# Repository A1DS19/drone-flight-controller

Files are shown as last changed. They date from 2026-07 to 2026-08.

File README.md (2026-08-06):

# Drone Flight Controller

A custom drone flight controller, designed in KiCad 10: an STM32F103R8T6 flight core paired with
an ATmega328P telemetry co-processor on a four-layer, ~102 × 49 mm PCB — taken from schematic
capture through placement, routing, clean ERC/DRC, and JLCPCB fabrication outputs
([pcb/production/](pcb/production/)).

## Features

- **STM32F103R8T6 flight core** — MPU-6050 IMU on I²C, four ESC/motor outputs, RC-receiver and
  TF-Luna LIDAR inputs, USB with ESD protection, SWD debug
- **ATmega328P telemetry co-processor** — nRF24L01P 2.4 GHz radio with SMA antenna connector,
  CH340G USB-serial, microSD logging over SPI, 5 V ↔ 3.3 V level shifting
- **Power tree** — XT60 battery input → LM7805 (5 V) → AMS1117 (3.3 V), filtered analog rail,
  battery-voltage sensing
- **0.96″ OLED** status display
- **Four-layer board** — solid internal ground plane, dedicated power planes, 71-line LCSC BOM,
  JLCPCB-ready Gerbers

## Screenshots

| Front | Back |
|---|---|
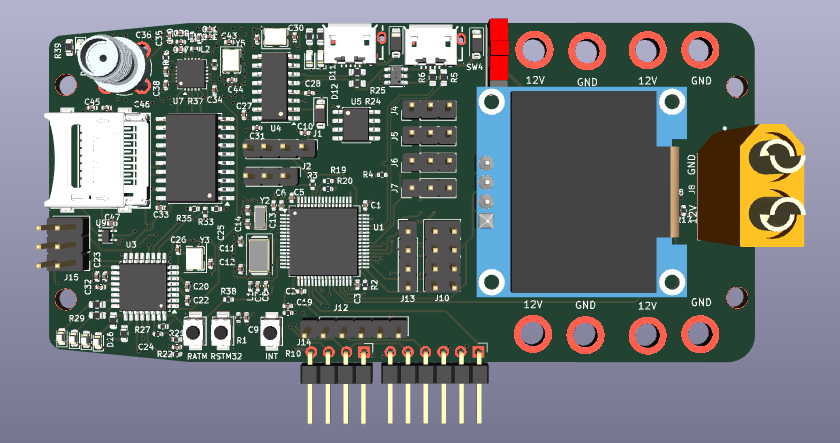
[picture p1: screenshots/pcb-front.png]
Board front
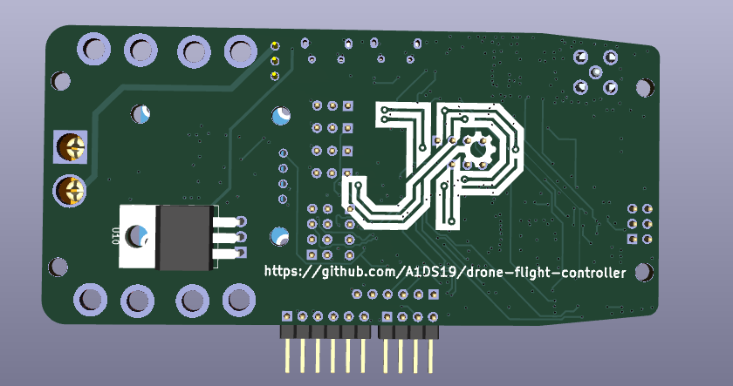
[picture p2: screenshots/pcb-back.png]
Board back
|  |  |

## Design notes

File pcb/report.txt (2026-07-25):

Info: Processing symbol 'R3:Resistor_SMD:R_0402_1005Metric'.
Info: Processing symbol 'U11:Package_TO_SOT_SMD:SOT-223-3_TabPin2'.
Info: Processing symbol 'U10:Package_TO_SOT_THT:TO-220-3_Horizontal_TabDown'.
Info: Processing symbol 'J17:easyeda:SMA_142-0701-201'.
Info: Processing symbol 'L1:Inductor_SMD:L_0402_1005Metric'.
Info: Processing symbol 'L2:Inductor_SMD:L_0402_1005Metric'.
Info: Processing symbol 'L3:Inductor_SMD:L_0402_1005Metric'.
Info: Processing symbol 'L4:Inductor_SMD:L_0402_1005Metric'.
Info: Processing symbol 'R1:Resistor_SMD:R_0402_1005Metric'.
Info: Processing symbol 'R2:Resistor_SMD:R_0402_1005Metric'.
Info: Processing symbol 'Y1:Crystal:Crystal_SMD_5032-2Pin_5.0x3.2mm'.
Info: Processing symbol 'R4:Resistor_SMD:R_0402_1005Metric'.
Info: Processing symbol 'R5:Resistor_SMD:R_0402_1005Metric'.
Info: Processing symbol 'R6:Resistor_SMD:R_0402_1005Metric'.
Info: Processing symbol 'R7:Resistor_SMD:R_0402_1005Metric'.
Info: Processing symbol 'R8:Resistor_SMD:R_0402_1005Metric'.
Info: Processing symbol 'R9:Resistor_SMD:R_0402_1005Metric'.
Info: Processing symbol 'R10:Resistor_SMD:R_0402_1005Metric'.
Info: Processing symbol 'R11:Resistor_SMD:R_0603_1608Metric'.
Info: Processing symbol 'R12:Resistor_SMD:R_0603_1608Metric'.
Info: Processing symbol 'J8:easyeda:AMASS_XT60-M'.
Info: Processing symbol 'J3:easyeda:MICRO-USB-SMD_MICROXNJ_1'.
Info: Processing symbol 'Y5:Crystal:Crystal_SMD_SeikoEpson_TSX3225-4Pin_3.2x2.5mm'.
Info: Processing symbol 'Y4:Crystal:Crystal_SMD_SeikoEpson_TSX3225-4Pin_3.2x2.5mm'.
Info: Processing symbol 'Y3:Crystal:Crystal_SMD_SeikoEpson_TSX3225-4Pin_3.2x2.5mm'.
Info: Processing symbol 'C1:Capacitor_SMD:C_0402_1005Metric'.
Info: Processing symbol 'J4:Connector_PinHeader_2.54mm:PinHeader_1x03_P2.54mm_Vertical'.
Info: Processing symbol 'J5:Connector_PinHeader_2.54mm:PinHeader_1x03_P2.54mm_Vertical'.
Info: Processing symbol 'J6:Connector_PinHeader_2.54mm:PinHeader_1x03_P2.54mm_Vertical'.
Info: Processing symbol 'J7:Connector_PinHeader_2.54mm:PinHeader_1x03_P2.54mm_Vertical'.
Info: Processing symbol 'R13:Resistor_SMD:R_0603_1608Metric'.
Info: Processing symbol 'J9:Connector_PinHeader_2.54mm:PinHeader_1x06_P2.54mm_Horizontal'.
Info: Processing symbol 'J10:Connector_PinHeader_2.54mm:PinHeader_2x04_P2.54mm_Vertical'.
Info: Processing symbol 'J11:easyeda:OLED'.
Info: Processing symbol 'J12:Connector_PinHeader_2.54mm:PinHeader_1x06_P2.54mm_Vertical'.
Info: Processing symbol 'J13:Connector_PinHeader_2.54mm:PinHeader_1x04_P2.54mm_Vertical'.
Info: Processing symbol 'J14:Connector_PinHeader_2.54mm:PinHeader_1x04_P2.54mm_Horizontal'.
Info: Processing symbol 'J15:Connector_PinHeader_2.54mm:PinHeader_2x03_P2.54mm_Vertical'.
Info: Processing symbol 'J16:easyeda:MICRO-USB-SMD_MICROXNJ_1'.
Info: Processing symbol 'Y2:Crystal:Crystal_SMD_3215-2Pin_3.2x1.5mm'.
Info: Processing symbol 'SW4:easyeda:SW-TH_SHOU-HAN_SS12D10G4'.
Info: Processing symbol 'R34:Resistor_SMD:R_0603_1608Metric'.
Info: Processing symbol 'R35:Resistor_SMD:R_0402_1005Metric'.
Info: Processing symbol 'R36:Resistor_SMD:R_0402_1005Metric'.
Info: Processing symbol 'R37:Resistor_SMD:R_0402_1005Metric'.
Info: Processing symbol 'R38:Resistor_SMD:R_0402_1005Metric'.
Info: Processing symbol 'R39:Resistor_SMD:R_0603_1608Metric'.
Info: Processing symbol 'SW1:Button_Switch_THT:SW_PUSH_6mm_H9.5mm'.
Info: Processing symbol 'SW2:Button_Switch_THT:SW_PUSH_6mm_H9.5mm'.
Info: Processing symbol 'SW3:Button_Switch_THT:SW_PUSH_6mm_H9.5mm'.
Info: Processing symbol 'R33:Resistor_SMD:R_0402_1005Metric'.
Info: Processing symbol 'U1:Package_QFP:LQFP-64_10x10mm_P0.5mm'.
Info: Processing symbol 'U2:Sensor_Motion:InvenSense_QFN-24_4x4mm_P0.5mm'.
Info: Processing symbol 'U3:Package_QFP:TQFP-32_7x7mm_P0.8mm'.
Info: Processing symbol 'U4:Package_SO:SOIC-16_3.9x9.9mm_P1.27mm'.
Info: Processing symbol 'U5:Package_SO:SOIC-8_3.9x4.9mm_P1.27mm'.
Info: Processing symbol 'U6:Package_SO:SOIC-20W_7.5x12.8mm_P1.27mm'.
Info: Processing symbol 'U7:Package_DFN_QFN:QFN-20-1EP_4x4mm_P0.5mm_EP2.5x2.5mm'.
Info: Processing symbol 'U9:Package_TO_SOT_SMD:SOT-353_SC-70-5'.
Info: Processing symbol 'U8:easyeda:TF-SMD_472192001'.
Info: Processing symbol 'R23:Resistor_SMD:R_0603_1608Metric'.
Info: Processing symbol 'R14:Resistor_SMD:R_0603_1608Metric'.
Info: Processing symbol 'R15:Resistor_SMD:R_0603_1608Metric'.
Info: Processing symbol 'R16:Resistor_SMD:R_0603_1608Metric'.
Info: Processing symbol 'R17:Resistor_SMD:R_0402_1005Metric'.
Info: Processing symbol 'R18:Resistor_SMD:R_0402_1005Metric'.
Info: Processing symbol 'R19:Resistor_SMD:R_0402_1005Metric'.
Info: Processing symbol 'R20:Resistor_SMD:R_0402_1005Metric'.
Info: Processing symbol 'R21:Resistor_SMD:R_0402_1005Metric'.
Info: Processing symbol 'R22:Resistor_SMD:R_0402_1005Metric'.
Info: Processing symbol 'J2:Connector_PinHeader_2.54mm:PinHeader_1x03_P2.54mm_Vertical'.
Info: Processing symbol 'R24:Resistor_SMD:R_0402_1005Metric'.
Info: Processing symbol 'R25:Resistor_SMD:R_0402_1005Metric'.
Info: Processing symbol 'R26:Resistor_SMD:R_0402_1005Metric'.
Info: Processing symbol 'R27:Resistor_SMD:R_0402_1005Metric'.
Info: Processing symbol 'R28:Resistor_SMD:R_0603_1608Metric'.
Info: Processing symbol 'R29:Resistor_SMD:R_0603_1608Metric'.
Info: Processing symbol 'R30:Resistor_SMD:R_0402_1005Metric'.
Info: Processing symbol 'R31:Resistor_SMD:R_0603_1608Metric'.
Info: Processing symbol 'R32:Resistor_SMD:R_0603_1608Metric'.
Info: Processing symbol 'C31:Capacitor_SMD:C_0402_1005Metric'.
Info: Processing symbol 'C22:Capacitor_SMD:C_0402_1005Metric'.
Info: Processing symbol 'C23:Capacitor_SMD:C_0402_1005Metric'.
Info: Processing symbol 'C24:Capacitor_SMD:C_0402_1005Metric'.
Info: Processing symbol 'C25:Capacitor_SMD:C_0402_1005Metric'.
Info: Processing symbol 'C26:Capacitor_SMD:C_0402_1005Metric'.
Info: Processing symbol 'C27:Capacitor_SMD:C_0402_1005Metric'.
Info: Processing symbol 'C28:Capacitor_SMD:C_0402_1005Metric'.
Info: Processing symbol 'C29:Capacitor_SMD:C_0402_1005Metric'.
Info: Processing symbol 'C30:Capacitor_SMD:C_0402_1005Metric'.
Info: Processing symbol 'C21:Capacitor_SMD:C_0402_1005Metric'.
Info: Processing symbol 'C32:Capacitor_SMD:C_0402_1005Metric'.
Info: Processing symbol 'C33:Capacitor_SMD:C_0402_1005Metric'.
Info: Processing symbol 'C34:Capacitor_SMD:C_0402_1005Metric'.
Info: Processing symbol 'C35:Capacitor_SMD:C_0402_1005Metric'.
Info: Processing symbol 'C36:Capacitor_SMD:C_0402_1005Metric'.
Info: Processing symbol 'C37:Capacitor_SMD:C_0402_1005Metric'.
Info: Processing symbol 'C38:Capacitor_SMD:C_0402_1005Metric'.
Info: Processing symbol 'C39:Capacitor_SMD:C_0402_1005Metric'.
Info: Processing symbol 'C40:Capacitor_SMD:C_0402_1005Metric'.
Info: Processing symbol 'C11:Capacitor_SMD:C_0402_1005Metric'.
Info: Processing symbol 'C2:Capacitor_SMD:C_0402_1005Metric'.
Info: Processing symbol 'C3:Capacitor_SMD:C_0402_1005Metric'.
Info: Processing symbol 'C4:Capacitor_SMD:C_0402_1005Metric'.
Info: Processing symbol 'C5:Capacitor_SMD:C_0402_1005Metric'.
Info: Processing symbol 'C6:Capacitor_SMD:C_0402_1005Metric'.
Info: Processing symbol 'C7:Capacitor_SMD:C_0402_1005Metric'.
Info: Processing symbol 'C8:Capacitor_SMD:C_0402_1005Metric'.
Info: Processing symbol 'C9:Capacitor_SMD:C_0402_1005Metric'.
Info: Processing symbol 'C10:Capacitor_SMD:C_0402_1005Metric'.
Info: Processing symbol 'C41:Capacitor_SMD:C_0402_1005Metric'.
Info: Processing symbol 'C12:Capacitor_SMD:C_0402_1005Metric'.
Info: Processing symbol 'C13:Capacitor_SMD:C_0402_1005Metric'.
Info: Processing symbol 'C14:Capacitor_SMD:C_0402_1005Metric'.
Info: Processing symbol 'C15:Capacitor_SMD:C_0402_1005Metric'.
Info: Processing symbol 'C16:Capacitor_SMD:C_0402_1005Metric'.
Info: Processing symbol 'C17:Capacitor_SMD:C_0402_1005Metric'.
Info: Processing symbol 'C18:Capacitor_SMD:C_0402_1005Metric'.
Info: Processing symbol 'C19:Capacitor_SMD:C_0402_1005Metric'.
Info: Processing symbol 'C20:Capacitor_SMD:C_0402_1005Metric'.
Info: Processing symbol 'FB2:Inductor_SMD:L_0805_2012Metric'.
Info: Processing symbol 'D10:Diode_SMD:D_SOD-123'.
Info: Processing symbol 'D11:LED_SMD:LED_0603_1608Metric'.
Info: Processing symbol 'D12:LED_SMD:LED_0603_1608Metric'.
Info: Processing symbol 'D13:LED_SMD:LED_0603_1608Metric'.
Info: Processing symbol 'D14:LED_SMD:LED_0603_1608Metric'.
Info: Processing symbol 'D15:LED_SMD:LED_0603_1608Metric'.
Info: Processing symbol 'D16:LED_SMD:LED_0603_1608Metric'.
Info: Processing symbol 'D18:LED_SMD:LED_0603_1608Metric'.
Info: Processing symbol 'FB1:Inductor_SMD:L_0805_2012Metric'.
Info: Processing symbol 'D9:LED_SMD:LED_0603_1608Metric'.
Info: Processing symbol 'H1:easyeda:MountingHole_3.5mm_5.5mm'.
Info: Processing symbol 'H2:easyeda:MountingHole_3.5mm_5.5mm'.
Info: Processing symbol 'H3:easyeda:MountingHole_3.5mm_5.5mm'.
Info: Processing symbol 'H4:easyeda:MountingHole_3.5mm_5.5mm'.
Info: Processing symbol 'H5:easyeda:MountingHole_3.5mm_5.5mm'.
Info: Processing symbol 'H6:easyeda:MountingHole_3.5mm_5.5mm'.
Info: Processing symbol 'H7:easyeda:MountingHole_3.5mm_5.5mm'.
Info: Processing symbol 'H8:easyeda:MountingHole_3.5mm_5.5mm'.
Info: Processing symbol 'J1:Connector_PinHeader_2.54mm:PinHeader_1x04_P2.54mm_Vertical'.
Info: Processing symbol 'C51:Capacitor_SMD:C_1206_3216Metric'.
Info: Processing symbol 'C42:Capacitor_SMD:C_0402_1005Metric'.
Info: Processing symbol 'C43:Capacitor_SMD:C_0402_1005Metric'.
Info: Processing symbol 'C44:Capacitor_SMD:C_0402_1005Metric'.
Info: Processing symbol 'C45:Capacitor_SMD:C_0402_1005Metric'.
Info: Processing symbol 'C46:Capacitor_SMD:C_0402_1005Metric'.
Info: Processing symbol 'C47:Capacitor_SMD:C_0402_1005Metric'.
Info: Processing symbol 'C48:Capacitor_SMD:C_1206_3216Metric'.
Info: Processing symbol 'C49:Capacitor_SMD:C_1206_3216Metric'.
Info: Processing symbol 'C50:Capacitor_SMD:C_1206_3216Metric'.
Info: Processing symbol 'D1:Diode_SMD:D_SOD-123'.
Info: Processing symbol 'D2:Diode_SMD:D_SOD-123'.
Info: Processing symbol 'D3:PCM_JLCPCB:SOT-23-6_L2.9-W1.6-P0.95-LS2.9-BL'.
Info: Processing symbol 'D4:LED_SMD:LED_0603_1608Metric'.
Info: Processing symbol 'D5:LED_SMD:LED_0603_1608Metric'.
Info: Processing symbol 'D6:LED_SMD:LED_0603_1608Metric'.
Info: Processing symbol 'D7:LED_SMD:LED_0603_1608Metric'.
Info: Processing symbol 'D8:LED_SMD:LED_0603_1608Metric'.
Warning: No net found for component J3 pad 6 (no pin 6 in symbol).
Warning: No net found for component U7 pad 21 (no pin 21 in symbol).
Warning: No net found for component J16 pad 6 (no pin 6 in symbol).
Warning: No net found for component J16 pad 6 (no pin 6 in symbol).
Warning: No net found for component J16 pad 6 (no pin 6 in symbol).
Warning: No net found for component J16 pad 6 (no pin 6 in symbol).
Warning: No net found for component J3 pad 6 (no pin 6 in symbol).
Warning: No net found for component J3 pad 6 (no pin 6 in symbol).
Warning: No net found for component J3 pad 6 (no pin 6 in symbol).
Error: J3 pad SH not found in easyeda:MICRO-USB-SMD_MICROXNJ_1.
Error: J16 pad SH not found in easyeda:MICRO-USB-SMD_MICROXNJ_1.

Info: Total warnings: 9, errors: 2.

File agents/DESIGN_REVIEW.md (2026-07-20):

# Drone Flight Controller Design Review

**Date:** 2026-07-19
**Design format:** KiCad 10, two-sheet hierarchical schematic, nominal two-layer PCB
**Verdict:** Schematic capture is complete, the first native ERC ran clean (0/0, 2026-07-19), and
footprints are assigned to every component and imported into the board. Layout (outline, placement,
routing) can begin. The BOM is fully sourced (sourcing gate PASS, 2026-07-20); fabrication now
waits only on placement, routing, and DRC.

## Critical findings

| Severity | Finding | Evidence |
|---|---|---|
| Blocker | The PCB has all 158 footprints imported (2026-07-19) but no outline, placement, routing, or zones yet. | `drone-flight-controller.kicad_pcb` |
| Resolved | The full BOM is sourced (2026-07-20): all ~150 remaining refs — every IC, passive, LED, diode, crystal, RF inductor, ferrite, and connector — carry LCSC/Part/Manufacturer fields resolved against the offline catalog. `lcsc.py gate --min-stock 100`: **PASS, 0 blocking**, 26 Extended lines (~$78 max setup; THT lines are hand-solder). Physical deltas: `Y2` footprint 2012 → 3215 (Basic Epson FC-135 class), `FB1`/`FB2` value typo fixed to `120R@100MHz` (3 A power bead). Selection rules and notable calls in `pcb/parts-log.md`. | BOM gate 2026-07-20 |
| Resolved | The USB shield gap from the Update-PCB import is fixed (2026-07-19): J3/J16's shield pin was renumbered "SH" → "6" to match the footprint's shell pads and tied to GND (`#PWR0142`/`#PWR0143`). Re-run Update PCB to carry it onto the board. `U7`'s exposed pad (footprint pad 21, no symbol pin) is **intentionally unconnected**: the nRF24L01+ Product Specification v1.0, page 65, recommends keeping the die attach pad unconnected — the recurring import warning for pad 21 is expected and benign. (The former SW1–SW3 pad-3/4 warnings disappeared with the TC-6610 swap: the official footprint's paired 1,1,2,2 pads all map.) | Netlist import log, nRF24L01+ PS v1.0 p. 65 |
| Resolved | Headless KiCad 10 checks are available after all: the AppImage bundles `kicad-cli` 10.0.4 at `/home/dev/Applications/kicad-10/AppDir/bin/kicad-cli` (discovered 2026-07-19; ERC verified working). The system `kicad-cli` 9.0.9 still cannot load these files — use the AppImage path. | `kicad-cli version` → 10.0.4 |
| Resolved | `L1` is now a Murata BLM15AG601SN1D 600 Ω@100 MHz ferrite bead (LCSC C76884, 0402), and `C8` was corrected 100 nF → 10 nF so VDDA carries the datasheet-exact 10 nF + 1 µF (DS5319 Rev 20, Figure 14, p. 36). The bead itself is ST application practice (AN2586 / ST eval boards), not a Figure-14 element — recorded in `agents/decisions.md`. | Root schematic, Murata ref spec p. 1 |
| Resolved | First native ERC ran clean on 2026-07-19 (0 errors / 0 warnings, KiCad 10 GUI) after: `PWR_FLAG`s on the passive-fed rails (`+12V`, `+12C`, `VDDA`, the FB1→LM7805 node, `Vdrive`) and one on `GND`; a no-connect on `SW4`'s unused throw; the USB shell GND pins retyped to passive; and a real bug fix — `U4` (CH340G) had VCC and V3 cross-wired, leaving the chip unpowered with its internal 3.3 V node tied to 5 V. | `pcb/ERC.rpt` 2026-07-19T16:54 |
| Warning | The telemetry subsheet has no sheet pins; all cross-sheet connectivity rides on global labels and power symbols. Functional, but every net is effectively global, and the I²C buses are named `12C1_*`/`12C2_*` (digit "12"), which text searches for "I2C" will miss. | Sheet definition + label scan |
| Warning | `pcb/sym-lib-table` now registers `custom-symbols` (microSD + the corrected `USB_B_Micro`, added 2026-07-20 after "Update Symbols from Library" twice restored the global lib's stale SH shield pin — J3/J16 now resolve project-locally, making that regression impossible). The DigiKey/PCM libraries still resolve only through the embedded cache and the user's global table. | `pcb/sym-lib-table` |

## What is present

Roughly 158 components across 82 named nets on two sheets.

**Sheet 1 — flight controller core** (`drone-flight-controller.kicad_sch`, 88 components):

| Subsystem | Parts |
|---|---|
| MCU | `U1` STM32F103R8T6, LQFP-64, footprint assigned |
| IMU | `U2` MPU-6050 (QFN-24) on I²C bus `12C2_*` |
| Clocks | `Y1` 8 MHz HSE (20 pF loads), `Y2` 32.768 kHz LSE (10 pF loads) |
| Power | `J8` XT-60 → `SW4` master switch (SS12D10G5, LCSC C7431054) → `U10` LM7805 (TO-220) → `U11` AMS1117-3.3 (SOT-223); `FB1`/`FB2` ferrites, `D1`/`D2` B5819W Schottkys, `R17`/`R18` 47k/15k battery divider → `ADC_Vbat` |
| Reset/boot | `SW1` (TC-6610, LCSC C7528713) + `R1` 10k + `C9` 100 nF on NRST; `J2` boot jumper + `R3` 10k on BOOT0 |
| USB | `J3` micro-B (MicroXNJ, LCSC C404969) with `D3` SRV05-4A ESD array (LCSC C20615829) |
| I/O | `J1` SWD, `J4`–`J7` ESC/motor, `J9` TF-Luna LIDAR, `J10` RC receiver (`MANDO_1..6`), `J11` OLED, `J12`–`J14` SPI/I²C/USART expansion |
| Misc | Status LEDs, `SW2` user button (`BOTON`, TC-6610), `H1`–`H4` mounting pads on `+12V`, `H5`–`H8` on `GND` |

**Sheet 2 — telemetry** (`ATMEGA238P-plus-components.kicad_sch`, hierarchical subsheet, 70 components):

| Subsystem | Parts |
|---|---|
| MCU | `U3` ATMEGA328P-AU (TQFP-32), `Y3` 16 MHz, `J15` ICSP, `SW3` reset (TC-6610) |
| Radio | `U7` nRF24L01P (QFN-20), `J17` coaxial antenna, `L2`–`L4` matching, `Y5` 16 MHz |
| USB-serial | `U4` CH340G (SOIC-16), `J16` micro-B (MicroXNJ), `Y4` 12 MHz |
| Level shift | `U6` 74HC245, `U9` 74AHC1G125 (5 V ↔ 3.3 V SPI) |
| Storage | `U8` microSD socket (LCSC C164170), SPI-mode wired: CS=`CS_SD_74HC245`, MOSI/CLK from the 74HC245, MISO=`MISO_SD_OUT` via `U9`, VDD=+3.3V, VSS+shell=GND, DAT1/DAT2 no-connected |
| Analog | `U5` LM358 dual op-amp on the RX/TX path |

## Power network

```text
J8 XT-60 (+12V) --- SW4 --- (+12C) --- FB1 --- U10 LM7805 --- (+5V) --- U11 AMS1117-3.3 --- (+3.3V)
      |                                                          |                             |
      R17/R18 divider -> ADC_Vbat                                FB2 -> Vdrive (5 V)           L1 600R bead -> VDDA
                                                                                                +-- C7: 1 uF
GND ---------------------------------------------------------------------------------------- +-- C8: 100 nF
```

- The STM32 digital decoupling matches the datasheet: Figure 14 on page 36 calls for five 100 nF
  capacitors plus one 4.7 uF on VDD3, and the schematic has the corresponding quantities.
- VDDA now matches the figure exactly: 10 nF (`C8`) + 1 uF (`C7`) behind `L1`, a 600 Ω@100 MHz
  ferrite bead per ST application practice (see `agents/decisions.md`).
- `+12C` is the switched 12 V node between `SW4` and `FB1` — intentional naming, not a stray net.
- `PWR_FLAG`s were added 2026-07-19 on the passive-fed rails (`+12V`, `+12C`, `VDDA`, FB1→LM7805,
  `Vdrive`) and once on `GND`. Two GND symbol libraries remain mixed (`power:GND` and
  `PCM_SparkFun-PowerSymbol:GND`), which is cosmetic only.

## Reset and boot

Both prior blockers are resolved in the schematic:

- NRST: internal 30–50 kΩ pull-up (datasheet Table 39, page 66) plus external `R1` 10 kΩ to +3.3 V,
  `C9` 100 nF (matching the recommended Figure 31, page 67 protection), and reset button `SW1`.
- BOOT0: `U1` pin 60 runs through `R3` 10 kΩ to the center pin of boot-select jumper `J2`, whose outer
  pins sit on +3.3 V and GND. Per `decisions.md`, the default strap must be the GND (user-Flash)
  position — confirm the shipped jumper orientation at assembly.

## PCB and EMC

All 158 footprints are imported and the 95 mm frame outline template is placed; placement and
routing have not started, so no EMC review yet. Once placement begins, use
a continuous ground plane, place each bypass capacitor adjacent to its VDD/VSS pair, keep the VDDA
filter local to the MCU, keep the nRF24 antenna matching and feed clear of the power section, and keep
motor/ESC return currents away from the IMU and `ADC_Vbat` sensing.

## Project rules and compatibility

- Only the default net class exists: 0.20 mm clearance, 0.20 mm track, 0.60/0.30 mm via, 0.50 mm
  copper-to-edge. No power, RF, analog, or clock classes yet.
- Files are KiCad 10 (schematic `20260306`, PCB `20260206`). The system `kicad-cli` 9.0.9 cannot
  load them; use the AppImage CLI (`/home/dev/Applications/kicad-10/AppDir/bin/kicad-cli`, 10.0.4).
- `pcb/fp-lib-table` registers the `easyeda` footprint library; `pcb/sym-lib-table` is empty (see
  findings). Both lib tables are tracked in git.

## Analyses performed

- Structural s-expression inspection of both schematic sheets: performed
- Net connectivity extraction (KiCad parser): performed — 82 named nets
- Pin-geometry verification of `U8` attachments (wires, labels, no-connects, power symbols): performed
- Footprint/MPN property scan across all components: performed
- Native ERC (KiCad 10 GUI): performed 2026-07-19 — clean after the seven initial errors were fixed
- Update-PCB-from-schematic import of all 158 footprints: performed 2026-07-19 (2 errors / 19
  warnings logged; see findings)
- STM32 datasheet cross-check of power, reset, and boot networks: performed (carried forward and
  re-verified against the current schematic)

## Not performed / review limits

- Native DRC: not yet run (board has no layout); headless ERC/DRC remain blocked by the 9.0.9 CLI.
- Pin-level datasheet verification of the telemetry subsheet (ATmega328P, nRF24L01P, CH340G, 74HC245,
  74AHC1G125, microSD): not performed — only the STM32 power/reset/boot network is formally checked.
- SPICE, Gerber/DFM, lifecycle/sourcing: not applicable yet (no layout; MPN coverage is four parts).

## Recommended next sequence

1. Re-run Update PCB from Schematic to carry the USB-shield fix onto the board, and re-run ERC
   (expected to stay clean; the two new GND symbols sit on the already-driven GND net).
2. Resolve `L1` (real inductor or ferrite value; it now carries an L_0402 footprint but the `27nF`
   value is still invalid).
3. Register the project symbol libraries in `pcb/sym-lib-table` and note the board's new external
   footprint-library dependencies (`digikey-footprints`, `PCM_JLCPCB`) resolve only through the
   global table.
4. Assign MPNs/LCSC to the remaining ~154 parts, including a latching, adequately rated part for
   the `SW4` master switch.
5. Define outline, stackup, net classes, ground plane; place and route.
6. Run KiCad 10 DRC, cross-domain/EMC review, BOM/MPN review, and Gerber/DFM checks before fabrication.

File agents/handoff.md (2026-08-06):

# Session handoff — 2026-07-30

## What was done (this session)
- **Crystal-placement review** (user's request, all 5 crystals): the AN2867 Fig-14 moated
  In1 islands are sound — tight loops (caps 1.4–2.8 mm, MCU pins 3.3–6.3 mm), full island
  coverage under every crystal, guard rings + stitching on Y3/Y5, 0 blocking. Found the
  STM32 islands' single-point bridges sat AWAY from the trace-entry corridor: all four
  HSE/LSE nets crossed the moat over voids (ZONE-REF worst 0% reference).
- **Fixed the STM32 bridges** (AppImage pcbnew, not MCP): two micro-bridges replaced by one
  L-shaped `GND bridge osc stm32` at (122.5,97.2)–(126.5,100.4), top edge stepped to
  y=97.45 for x>124.2 to clear the +3.3V via at (124.9,96.6). Islands now merge through
  one neck under U1 pins 3–6. Zones gate 21→17 warnings / 0 blocking; DRC violation
  histogram byte-identical pre/post (401, all pre-existing).
- **Skills** (claude-configs branch `feat/osc-bridge-at-entry`, commit 0df4ab8, NOT pushed):
  CHECKLIST 5.8 (bridge under trace entry) + digest line 6, design-rules 16b extension,
  zones.py `osc_nets` model key + `[oscillator net]` ZONE-REF annotation with the
  bridge-at-entry recommendation. Suites 85/3/97 green (+1 new test).

## Current state
- Drone tree UNCOMMITTED: user's zone/crystal/routing WIP plus today's bridge fix in
  `.kicad_pcb`; `.kicad_pro` modified; crystal datasheets (AN2867, SPMA056) untracked.
- Osc clusters are locally routed on F.Cu (the 07-27 "1 segment" note is stale).
- Open board items: (1) NRF_XC1 still 50% covered — Y5's bridge is at the entry but
  narrow, user scoped today's fix to STM32 only; (2) NEW: `+3.3V` In2 zone splits into
  2 disconnected regions — resolve before routing; (3) `+12C` PCB-only net (stale sync,
  from 07-27); (4) H1-H8/J8/J17 pads → SOLID; (5) sliver island-removal limits ~2 mm²
  (GND/In1 ×3, +5V/In2 ×6); (6) Y4 is 2.1 mm from board edge (noted, course design);
  (7) two different zones both named "GND bridge osc 1 atm328p" (nRF + CH340G bridges) —
  rename for auditability; (8) board 102×49 mm under JLCPCB 70×70 Standard-assembly floor.
- Standing gotchas: KiCAD-MCP-Server process runs in background — MCP edits corrupt the
  designator cache AND a stale MCP/GUI save can wipe work; close KiCad + avoid MCP for
  file edits; commit before risky GUI ops. Pre-edit board backup in session scratchpad.

## Plan for next session
1. Commit the drone WIP on a feature branch (zones + crystal placement + bridge fix).
2. Push `feat/osc-bridge-at-entry` in claude-configs and open the PR (user to confirm).
3. Fix open items 1–5 (+7 rename), re-run `pcb-verify/scripts/zones.py` (AppImage recipe
   in memory) — expect NRF_XC1 and the sliver/thermal warnings to clear.
4. Then routing per the 07-27 plan: signals on F.Cu over solid In1 GND; B.Cu short jogs
   only, never USB D± across In2 splits; via fanout → `gnd_vias.py` stitch → refill → DRC.

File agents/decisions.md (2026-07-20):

# Decisions

## 2026-07-20 — VDDA filter: 600 Ω ferrite bead + datasheet-exact 10 nF/1 µF
`L1` (long an invalid `27nF` placeholder) is a Murata BLM15AG601SN1D 600 Ω@100 MHz ferrite bead
(LCSC C76884, 0402, 300 mA/0.62 Ω max DCR vs ~1.5 mA VDDA draw), and `C8` was corrected
100 nF → 10 nF so VDDA carries exactly the 10 nF + 1 µF of DS5319 Rev 20 Figure 14 (p. 36).
Provenance split, deliberately recorded: the capacitor values come from the STM32 datasheet; the
bead does NOT appear in Figure 14 — it follows ST application practice (AN2586, ST eval-board
BOMs) and this design's own intent of isolating the ADC reference from digital-rail noise
(ESC switching near the `ADC_Vbat` battery divider). Removing the bead would be
datasheet-literal but strictly worse here.

## 2026-07-14 — Linear power tree: XT-60 battery → LM7805 → AMS1117-3.3
Battery power enters on an XT-60 connector (J8) through master switch SW4 onto `+12V`, then through
cascaded linear regulators: LM7805 to `+5V` and AMS1117-3.3 to `+3.3V`, with ferrite-filtered
`Vdrive` (5 V) and `VDDA` (3.3 V analog) branches. Linear regulation was chosen over switching for
noise simplicity at the cost of efficiency and heat in the 12 V → 5 V drop. Moving to a switcher
later means redesigning the power section and its layout.

## 2026-07-14 — microSD socket from a converted EasyEDA footprint (LCSC C164170)
The microSD socket (U8) has no KiCad-official footprint, so the LCSC part C164170 was converted with
`easyeda2kicad` into project-local libraries: symbol in `pcb/libs/custom-symbols.kicad_sym`,
footprint `easyeda:TF-SMD_472192001`, STEP/WRL models in `pcb/libs/easyeda.3dshapes/`. This pins the
design to the orderable LCSC part. Gotcha: with `--project-relative`, the tool emits a doubled
`pcb/pcb/` 3D-model path (KIPRJMOD already points at `pcb/`) that must be fixed by hand after every
re-conversion.

## 2026-07-12 — ATmega328P-AU telemetry co-processor on its own subsheet
Telemetry — the nRF24L01P 2.4 GHz link, CH340G USB-serial, and microSD logging — runs on a dedicated
ATmega328P-AU instead of loading the STM32, keeping RF and logging off the flight-control MCU. It is
captured as the hierarchical subsheet "ATMEGA238P" (`ATMEGA238P-plus-components.kicad_sch`), connected
to the root sheet through global labels and shared rails rather than sheet pins. Folding this back
into a single MCU would re-architect the schematic and both pin maps.

## 2026-07-12 — Adopt the new-project doc structure
Scaffolded root `CLAUDE.md` plus `agents/{CONTEXT,roadmap,decisions}.md` so the repo matches the
`/new-project` skill's canonical layout and a future run refines rather than clobbers. The Codex
`AGENTS.md` is kept alongside it — the two conventions coexist and are cross-linked, not merged.

## 2026-07-11 — KiCad 10 file formats (not backward-compatible)
The design is saved in KiCad 10 formats (schematic `20260306`, PCB `20260206`). KiCad 9 reports
"Failed to load" for both files, so KiCad 10+ is mandatory for every contributor and for CI/CLI checks.
Reverting to KiCad 9 would require re-authoring the design; treated as one-way.

## 2026-07-11 — STM32F103R8T6 (LQFP-64) as the MCU
The flight-controller core is fixed to the STM32F103R8T6 in LQFP-64. The pin map, power topology, and
footprint choices downstream all depend on this part, so changing it is a re-layout.

## 2026-07-11 — Two-layer PCB stackup
The board targets a nominal two-layer stackup. This constrains ground-plane strategy, routing density,
and impedance control; moving to four layers later would be a significant re-spin.

## 2026-07-11 — BOOT0 defaults to user-Flash boot
BOOT0 will be pulled to its user-Flash-boot state by default, with any system-memory (ROM bootloader)
entry exposed as a deliberate, controlled override rather than the resting state.

## 2026-07-11 — Codex AGENTS.md only; no .codex/config.toml
Repository agent instructions live in `AGENTS.md`. A project `.codex/config.toml` is intentionally
omitted because no repo-specific model, sandbox, MCP, or hook setting is required.

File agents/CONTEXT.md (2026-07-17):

# Drone Flight Controller — Context

Canonical vocabulary for a custom STM32F103-based drone flight-controller PCB. Domain terms only; see
`decisions.md` for choices and `roadmap.md` for scope.

## Board & parts

**Flight controller**:
The board being designed — the electronics that read sensors and drive the motor ESCs to stabilise a
drone. Schematic capture is complete (two hierarchical sheets); the PCB layout has not been started.

**MCU**:
The STM32F103R8T6 (LQFP-64), `U1` — the flight-control core on the root sheet.
_Avoid_: processor, CPU.

**Telemetry MCU**:
The ATmega328P-AU (TQFP-32), `U3` — a co-processor on the subsheet that owns the radio link, USB-serial,
and microSD logging. Note: the subsheet and its filename spell it "ATMEGA238P"; the part is a 328P.

**Radio**:
The nRF24L01P 2.4 GHz transceiver (`U7`) with coaxial antenna connector `J17` and an L-network match
(`L2`–`L4`).

**microSD socket**:
`U8`, LCSC C164170 — project-local symbol `custom-symbols:MICROSD_C164170`, footprint
`easyeda:TF-SMD_472192001`. Wired for SPI-mode access with a grounded shell; pin electrical types are
set per function (VDD/VSS `power_in`, DAT0 `output`, CMD/DAT `bidirectional`, shell tabs `passive`).

**Level shifting**:
74HC245 (`U6`) and 74AHC1G125 (`U9`) moving the SPI bus between the 5 V and 3.3 V domains.

**Decoupling network** (a.k.a. bypass network):
The 100 nF capacitors placed one per VDD/VSS pin pair plus the 4.7 uF bulk capacitor on VDD3, per the
STM32 datasheet Figure 14. Their job is local charge delivery and supply-noise suppression.
_Avoid_: filter caps.

**Bulk capacitor**:
The single 4.7 uF device on the digital supply that backs the per-pin 100 nF caps.

**VDDA filter**:
The L–C network feeding the analog supply (VDDA) from the digital rail to keep ADC/PLL noise down.
Inductor `L1` still carries an invalid `27nF` value and no footprint — its electrical intent is
unresolved.

**BOOT0**:
The STM32 pin that selects the startup boot source (user Flash vs system-memory bootloader). No longer
floating: strapped through `R3` (10 kΩ) to boot-select jumper `J2` (+3.3 V / GND). User-Flash boot is
the intended default strap position.

**NRST**:
The MCU reset pin. Has a permanent internal 30–50 kΩ pull-up; externally it also gets `R1` (10 kΩ) to
+3.3 V, `C9` (100 nF), and reset button `SW1` on net `RST`.

## Rails & nets

**Rail**:
A named supply net. The power tree is: `+12V` (XT-60 battery input `J8`) → `SW4` master switch →
`+12C` (switched 12 V; "C" as in *conmutado*) → `FB1` → LM7805 → `+5V` → AMS1117-3.3 → `+3.3V`.
Derived rails: `Vdrive` (ferrite-filtered 5 V branch) and `VDDA` (filtered analog 3.3 V). Plus `GND`.
No `PWR_FLAG` symbols exist yet, so ERC will report undriven power inputs on these rails.

**Net-name quirks**:
Labels are partly Spanish — `BOTON` (user button), `MANDO_1..6` (RC-receiver channels), LED values
`ROJO`/`VERDE`/`AZUL`. The I²C buses are labelled `12C1_*` and `12C2_*` with a digit "12", not "I2" —
searches for "I2C" will miss them.

**Net class**:
A KiCad group of nets sharing clearance/width/via rules. Only the `Default` class is defined
(0.20 mm clearance, 0.20 mm track, 0.60/0.30 mm via).

## Tooling & review

**ERC** (Electrical Rules Check):
KiCad's schematic-level rule check. Run with `kicad-cli sch erc` — the CLI must come from KiCad 10;
the 9.x CLI fails with "Failed to load". Native ERC has never been run on this design.

**DRC** (Design Rules Check):
KiCad's PCB-level rule check. Run with `kicad-cli pcb drc` (same KiCad 10 requirement). Not meaningful
yet — the board is empty.

**MPN** (Manufacturer Part Number):
The orderable part identifier attached to a component. Coverage is one part: `D3` (SRV05-4A,
LCSC C20615829). DigiKey-sourced symbols (`U3`, `U5`) carry MPN-like values but no explicit MPN field.

**Footprint**:
The physical land pattern a schematic symbol maps to on the PCB. Assigned only on the ten major ICs
(`U1`–`U5`, `U7`, `U8`, `U10`, `U11`, `D3`); every passive, connector, crystal, switch, and LED —
roughly 148 of 158 components — still has none.

**Source files**:
The hand-editable KiCad files: `.kicad_pro`, the two `.kicad_sch` sheets, `.kicad_pcb`, plus the
project libraries (`pcb/libs/`, `sym-lib-table`, `fp-lib-table`). Everything else (`.kicad_prl`,
backups, lock files, exports) is local or generated.

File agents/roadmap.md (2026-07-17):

# Roadmap

## Goal
A fabrication-ready two-layer STM32F103 flight controller: complete 3.3 V power tree, IMU and flight
sensors, ESC/motor and receiver/telemetry I/O, SWD debug, and a clean ERC/DRC + Gerber/DFM review.

## Milestones
- [x] Settle requirements: 12 V battery on XT-60, MPU-6050 IMU + TF-Luna LIDAR, RC receiver +
      nRF24L01P telemetry, three-pin ESC interface, USB + SWD debug, two-layer board. Board
      dimensions and mounting pattern get finalized during layout.
- [x] Add input protection and the power tree: XT-60 → SW4 master switch → `+12C` → LM7805 (`+5V`) →
      AMS1117-3.3 (`+3.3V`), with `Vdrive`/`VDDA` branches and a battery-sense divider. The current
      and noise budget is still undocumented.
- [x] Add BOOT0 default (R3 + boot-select jumper J2), NRST reset circuit (R1 pull-up, C9, SW1), and
      SWD debug header (J1).
- [x] Add the IMU and remaining flight-control interfaces: MPU-6050 on I²C, four ESC outputs,
      RC-receiver header, LIDAR, OLED, and SPI/I²C/USART expansion headers.
- [x] Add the telemetry subsystem: ATmega328P subsheet with nRF24L01P radio, CH340G USB-serial,
      microSD logging, and 5 V ↔ 3.3 V level shifting.
- [ ] Resolve the `L1` VDDA filter definition; add `PWR_FLAG`s to the rails; assign footprints + MPNs
      to every part (today: footprints on the ten major ICs only, one LCSC number).
- [ ] Run KiCad 10 ERC clean (needs a KiCad 10 `kicad-cli` — 9.0.9 cannot load the files), then
      update the PCB from the schematic.
- [ ] Define board outline, stackup, net classes, placement constraints, ground plane, and routing.
- [ ] Run KiCad 10 DRC, cross-domain/EMC review, BOM/MPN review, and Gerber/DFM checks before fabrication.

## Later / maybe
- Dedicated power, high-current, analog, clock, and controlled-impedance net classes.
- OSD or additional telemetry interfaces beyond the nRF24L01P link.
- Datasheet-level pin-map verification of the ATmega328P/nRF24/CH340/microSD subsheet (only the STM32
  power/reset/boot network has been formally cross-checked so far).

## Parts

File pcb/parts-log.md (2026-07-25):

# Parts selection log

Entry format per the pcb-source selection guide (§7).

### Master power switch — SW4: K3-1204D (C145861) — supersedes SS-12D11-G030 below (rejected at placement for size, never reached the board)
- **Key specs:** SPDT shorting slide (latching), vertical top-actuated, 5 A / 120 V AC, 50,000 cycles,
  insulation ≥ 100 MΩ, dielectric 1,500 V RMS, −25~+80 °C, 1.6 mm travel; slim 10 × 2.5 mm body,
  three Ø0.9 pins at 2.55 mm pitch — ~25 mm² of board, 3.4× smaller than the original G5
- **Price/stock:** $1.03 @ qty 1 (priciest switch considered — irrelevant at qty 1–3), stock **3,067**
  (19 d-old snapshot; thinnest line in the BOM — re-verify with `parts_db.py --refresh` before ordering),
  Extended THT
- **Rationale:** user's hard requirement was minimum board footprint; every full-size slide failed size
  and every mini slide failed the electrical gate. This is the only part found that passes both:
  5 A vs the ~0.3–0.4 A logic-tree load ≈ 12× margin, in the smallest mechanical envelope available.
- **Alternatives considered (the gated hunt):** SS-12D11-G030 — user-rejected, footprint too big;
  SS12D10G6-WJ C7431059 — same verdict (~12.7 × 12.3 mm strip); MK-12C02 class — 1 A but 6 V rating
  under the 12 V rail; MINI MSK12CO2 C2681570 — 5 × 2.8 mm but DC 12 V **50 mA** (datasheet §1.1),
  6–8× under load, only viable gating a P-FET load switch (user declined the circuit change);
  SK/SS12D07 family C2939726/C431547 — **LCSC description says 500 mA, SHOU HAN datasheet §1.1 says
  300 mA** — at/over load, killed by the datasheet gate (catalog descriptions are not ratings)
- **Design notes:** footprint `easyeda:SW-TH_K3-1204D` — pad map CLEAN, exactly 3 pads, **pad 2 =
  middle = common** at ±2.50 mm (datasheet PCB layout says 2.55 pitch; 0.05 mm offset on Ø1.0 holes
  for ~0.65 mm pins is inside slop — converted footprint kept). Wiring carries over: pin 1 `+12V`
  throw, pin 2 `+12C` common, pin 3 unused + no-connect. Shorting (make-before-break) type — 
  irrelevant here since throw 3 is unconnected. Top-actuated: no board-edge placement constraint.
- **Datasheet:** pcb/datasheets/C145861-K3-1204D.pdf — typical-specs block: 5 A 120 V AC vs
  ~0.3–0.4 A @ 12 V load: ~12× margin; 50k cycles; middle-common shorting SPDT schematic; PCB layout
  3 × Ø0.90 at 2.55 mm

### Master power switch — SW4: SS-12D11-G030 (C17179526) — supersedes SS12D10G5 below
- **Key specs:** SPDT (1P2T) latching slide, right-angle/horizontal THT, 3 A / 50 V AC (datasheet §2 —
  the 250 V in the LCSC listing is the description's AC class; datasheet is authoritative), ≤30 mΩ,
  10,000 cycles, −40~+85 °C, 250 ±100 gf, 2.2 mm travel, 13.4 × 6.6 mm body, G030 = 3.0 mm shank
- **Price/stock:** $0.221 @ qty 1, stock **3,533** (19 d-old snapshot — thinnest line in the BOM,
  re-verify with `parts_db.py --refresh` before ordering), Extended THT (hand-solder, same as the G5)
- **Rationale:** user swap request. Right-angle lever actuates from the board edge — reachable once
  the drone is framed/boxed, which the vertical G5 was not; 3 A ≈ 8× margin over the ~0.3–0.4 A
  logic tree; 10k vs 3k cycle life; was the runner-up in the original SW4 selection
- **Alternatives considered:** keep SS12D10G5 — vertical actuation loses boxed access; SS-12D11-G040
  (C17179527) / G050 (C17179529) — longer 4/5 mm shanks if the frame needs more lever, same body
- **Design notes:** footprint `easyeda:SW-TH_5P-P4.70_SS-12D11-G030` — pads 1/2/3 terminals at
  4.7 mm pitch with **pad 2 = middle = common** (verified against datasheet PCB layout; matches
  existing wiring: pin 1 `+12V` throw, pin 2 `+12C` common, pin 3 unused + no-connect). Pads 4/5 are
  the bracket slots (Ø1.5 drills at 13.2 mm span, 8.4 mm behind the terminal row) — netless
  mechanical, TS24CA precedent; expect benign "pad 4/5 has no pin" F8 notes. NOT pad-compatible with
  the G5 footprint (4.7 vs 4.8 mm pitch, extra brackets). Right-angle: place at a board edge with
  the lever overhanging Edge.Cuts.
- **Datasheet:** pcb/datasheets/C17179526-SS-12D11-G030.pdf — circuit diagram: middle pole common;
  3 A / 50 V AC vs the ~0.3–0.4 A @ 12 V LM7805-branch load: fine; ≥100 MΩ insulation, 500 V AC
  dielectric; height-code table decodes G030 = 3.0 mm

### Tact switches — SW1 (STM32 reset), SW2 (user button), SW3 (ATmega reset): TS-1088-AR02016 (C720477) — supersedes TC-6610 below
- **Key specs:** SPST momentary, 50 mA / 12 VDC, 160 gf ±50 (1.6 N), 100,000 cycles, SMD 3.9 × 3.0 mm
  body, 2.0 mm height, Ø1.8 mm round top actuator, travel 0.2 ± 0.1 mm, −30~+80 °C
- **Price/stock:** $0.050 @ qty 1, stock 619,530 (catalog snapshot 19 d old — re-verify before order),
  **Basic** — removes one Extended feeder line and moves all three buttons from hand-solder THT to reflow
- **Rationale:** user re-prioritized: minimum footprint while keeping a tactile click. Land ~5.6 × 3.0 mm
  single-side vs the TC-6610's 6×6 body + four Ø1.1 mm through-holes — frees bottom-layer copper under
  all three buttons on the 2-layer board. The tall-actuator (9 mm through-frame) requirement is dropped.
- **Alternatives considered:** TS-1187A-B-A-B C318884 (Basic, $0.019, 1.58 M stock) — 7.0 × 4.5 mm land
  is only a modest XY win and its A-B/C-D shorted-pair topology re-opens the 4-pad trap; TS24CA revert
  (footprint already in libs) — side-press, Extended; TS-1088R-02026 C455280 — same body in 260 gf but
  Extended; ALPS SKTAACE010 C358621 — 2.6 × 1.6 mm IP67, smallest, but 0.11 mm travel ≈ no tactile feel
- **Design notes:** footprint `easyeda:SW-SMD_L3.9-W3.0-P4.45` — pad map CLEAN (pins 1,2 ↔ pads 1,2,
  no mechanical pads: the 4-pad shorted-pair hazard is structurally gone on this part). Pads
  1.23 × 1.86 mm at ±2.18 mm (5.59 mm outer span / 3.13 mm gap) vs datasheet welding drawing
  5.5 / 3.4 / 2.0 — same class, slightly more generous. 3D model `SW-SMD_L3.9-W2.9-H2.0-LS4.8`
  (H2.0 = 020 height code, LS4.8 lead span). Debounce networks C9/C19/C24 unchanged.
- **Datasheet:** pcb/datasheets/C720477-TS-1088-AR02016.pdf — 50 mA/12 VDC vs µA reset/GPIO switching:
  fine; contact ≤ 100 mΩ; insulation ≥ 100 MΩ; dielectric ≥ 250 VAC/1 min; decode AR02016 = stainless
  spring, no locating posts, 2.0 mm height, 160 gf; SPST single loop matches 2-pin `Switch:SW_Push`

### Jellybean sweep (2026-07-20) — full BOM sourced, ~142 refs across 61 groups
All remaining ICs, passives, LEDs, diodes, crystals, RF inductors, ferrites, and connectors were
resolved against the offline catalog (Basic > Preferred > Extended, then stock) and stamped with
LCSC/Part/Manufacturer/Datasheet fields. Gate: `lcsc.py gate --min-stock 100` → **PASS, 0
blocking**, 26 Extended lines (~$78 max setup; the THT lines are hand-solder so real SMT feeder
fees ≈ $40). Full mapping recoverable from the schematic fields; selection rules per the
pcb-source selection guide. The calls worth remembering:
- **ICs by exact MPN** (STM32F103R8T6 C46034, MPU-6050 C24112, ATMEGA328P-AU C14877, CH340G
  C14267, LM358DR C5423 — both units, SN74HC245DWR C10093, NRF24L01P-R C8791, SN74AHC1G125DCKR
  C151890, L7805CV C5189702, AMS1117-3.3 C6186 Basic; U8 microSD C164170 field added).
- **Crystals matched on load capacitance** to the repo's original datasheets: Y1 8 MHz 20 pF 5032
  (C115962), Y3/Y5 16 MHz 9 pF 3225 (C13738), Y4 12 MHz 20 pF 3225 (C9002) — all Basic YXC.
  **Y2 32.768 kHz**: Basic Epson FC-135 (C32346) is a 3215 body → footprint swapped 2012 → 3215.
- **C50/C51 polarized 10 µF** → AVX TAJA106K016RNJ (C7171, Basic) — the exact part of the repo's
  original tantalum datasheet.
- **nRF matching** L2/L3/L4 → Murata LQG15HS8N2J02D + Sunlord SDCL1005 (multilayer RF); 1/1.5 pF
  C0G. **FB1/FB2** → Murata BLM21PG121SN1D 120 Ω@100 MHz **3 A** (value typo "100Uhm" fixed).
- **C23 4.7 µF 6.3 V X5R on the 5 V rail**: derated but accepted as bulk (C307423, 3.8 M stock).
- **J17 SMA** → BWSMA-KWE-Z001 (C496551): right-angle THT; drawing p. 6 grid 5.1 mm / Ø1.4 legs
  verified against the existing 5.08 mm footprint. Headers → XFCN PZ254V series; J8 → AMASS XT60.

### VDDA filter bead — L1: BLM15AG601SN1D (C76884)
- **Key specs:** 600 Ω @ 100 MHz ±25 %, 300 mA rated, 0.52/0.62 Ω DCR, 0402, −55~+125 °C
- **Price/stock:** $0.005 @ qty 1, stock 234,099, Extended
- **Rationale:** resolves the `27nF` placeholder; canonical ST-practice analog-rail bead; keeps
  the already-assigned `Inductor_SMD:L_0402_1005Metric` footprint. Paired change: `C8`
  100 nF → 10 nF so VDDA carries the datasheet-exact 10 nF + 1 µF (DS5319 Fig. 14 p. 36).
- **Alternatives considered:** Sunlord GZ2012D601TF (C1017, 0805, Basic, no feeder fee, matches
  FB1/FB2's size) — user preferred the smaller canonical Murata; deleting L1 for the
  datasheet-literal direct VDD tie — rejected, see decisions.md.
- **Design notes:** symbol stays `Device:L_Small` (a FerriteBead symbol swap risks the
  label-on-pin wiring for zero electrical gain); DCR drop at ~1.5 mA VDDA draw is < 1 mV.
- **Datasheet:** pcb/datasheets/C76884-BLM15AG601SN1D.pdf — p. 1 rating table row verified
  (600 Ω ±25 %, 300 mA, DCR 0.52/0.62 Ω); p. 3 temp range

### Master power switch — SW4: SS12D10G5 (C7431054)
- **Key specs:** SPDT vertical slide, non-shorting, THT 12.7 × 6.7 mm, AC 125 V / 2 A, −25~+70 °C,
  3,000 cycles, 2.2 mm travel, 250 gf
- **Price/stock:** $0.154 @ qty 1, stock 35,124, Extended (THT → hand-solder at JLC)
- **Rationale:** user-selected; retires the last named unsourced part. ~2 A rating vs the
  ~0.3–0.4 A logic-tree load through the LM7805 branch: ~5× margin. Latching (unlike the momentary
  tact parts considered earlier); THT for vibration robustness.
- **Alternatives considered:** G-Switch SS-12D11-G030 (3 A, right-angle, 10k cycles) and
  SS-12D01-G040 (1 A) — user preferred this one; 3k-cycle life is a non-issue for a master switch.
- **Design notes:** footprint `easyeda:SW-TH_SHOU-HAN_SS12D10G4` (EasyEDA shares the footprint
  name across the SS12D10 G-series lever variants — the part ordered is the **G5**). Pads 1/2/3 at
  4.8 mm pitch, **pad 2 = middle = common** per the datasheet schematic — matches the existing
  wiring (pin 1 `+12V` = ON throw, pin 2 `+12C` common, pin 3 unused throw, no-connect flagged).
  Model path set to `${KIPRJMOD}/libs/easyeda.3dshapes/`.
- **Datasheet:** pcb/datasheets/C7431054-SS12D10G5.pdf — p. 1 drawing (pins, 4.8/9.6 mm layout,
  non-shorting SPDT schematic), p. 3 §1.1 rating AC 125 V 2 A, §4.5 hand-solder 270 °C/4 s

### USB connectors — J3 (STM32 USB), J16 (CH340G USB): MicroXNJ (C404969)
- **Key specs:** micro-B 5P female, right-angle SMD, shell on 4 THT legs; 1.8 A/contact, 30 V DC,
  ≤50 mΩ contact, 5,000 mating cycles
- **Price/stock:** $0.037 @ qty 1, stock 144,146, Extended
- **Rationale:** the previous footprint had unknown provenance, no 3D model, and no MPN — this
  closes all three at once with a high-stock part
- **Alternatives considered:** keep the mystery footprint and hunt for a matching model — rejected
  (no provenance is no basis for fab); SHOU HAN MICRO 5.9ZB5.0 (C2765187) — different shell-leg
  arrangement from the incumbent pad pattern
- **Design notes:** footprint `easyeda:MICRO-USB-SMD_MICROXNJ_1`; shell legs renumbered 7/8/9 → "6"
  so all four land on the symbols' Shield pin (GND) — same convention as the earlier SH→6 fix.
  Signal pads 1–5 at 0.65 mm pitch match the drawing's Pin1…Pin5. Model path set to
  `${KIPRJMOD}/libs/easyeda.3dshapes/`. Reflow ≤250 °C/10 s (datasheet §5.6).
- **Datasheet:** pcb/datasheets/C404969-MicroXNJ.pdf — 1.8 A / 30 V vs USB 5 V loads: ample;
  pin map and land pattern verified against the p. 1 drawing

### Tact switches — SW1 (STM32 reset), SW2 (user button), SW3 (ATmega reset): TC-6610 -6*6*9-260g (C7528713) — supersedes TS24CA below
- **Key specs:** SPST momentary, 50 mA / 12 VDC, 2.6 N (260 gf), 50,000 cycles, 6×6 mm THT body,
  tall 9 mm round actuator, pin grid 6.5 × 4.5 mm (4-Ø1.5 holes suggested)
- **Price/stock:** $0.030 @ qty 1, stock 17,377, Extended + through-hole (feeder fee, hand-solder at JLC)
- **Rationale:** user-selected; the tall 9 mm top-actuated button stays reachable above surrounding
  parts / through the frame, and the 260 gf feel resists accidental presses
- **Alternatives considered:** TS24CA C393942 (previous pick) — replaced: side-actuated low-profile
  SMD didn't suit the tall-button requirement; SMD 6×6 tacts — rejected in favor of THT strength
  for a frequently-pressed panel-style button
- **Design notes:** **4-pin shorted-pair hazard**: datasheet circuit + PCB drawing show the pins
  6.5 mm apart are internally connected; switching is across the 4.5 mm span. The easyeda footprint
  numbers pads 1/2/3/4 distinctly, which with a 2-pin symbol would strap nets across a shorted pair
  (STM32 held in reset) — so the **official `Button_Switch_THT:SW_PUSH_6mm_H9.5mm`** is used
  instead: pads numbered 1,1,2,2 with same-numbered pads on the 6.5 mm (shorted) axis; verified
  drop-in for `Switch:SW_Push`. H9.5 is the closest official height variant to this 9.0 mm part
  (footprint identical; 3D model 0.5 mm taller). Official drill (1.1 mm class) is tighter than the
  datasheet's generous Ø1.5 suggestion but standard for the 0.7 mm flat pins.
- **Datasheet:** pcb/datasheets/C7528713-TC-6610_-6_6_9-260g.pdf — 12 V/50 mA vs µA reset/GPIO
  switching: fine; contact resistance ≤ 50 mΩ; insulation ≥ 100 MΩ @ 250 VAC; SPST single loop
  matches the 2-pin symbol; existing C9/C19/C24 debounce networks unchanged

### Tact switches — SW1 (STM32 reset), SW2 (user button), SW3 (ATmega reset): TS24CA (C393942)
- **Key specs:** SPST momentary, 50 mA / 12 VDC, 1.6 N actuation, 20,000 cycles, side-actuated
  (right-angle), SMD 4.6 × 1.8 mm body with frame tabs
- **Price/stock:** $0.023 @ qty 1, stock 399,530, Extended (one-time feeder fee accepted)
- **Rationale:** user-selected; side actuation keeps the buttons reachable from the board edge
  once boxed, and one part number covers all three buttons
- **Alternatives considered:** Basic-library top-actuated tact switches (3×4 / 5.1×5.1 class) —
  rejected: would avoid the Extended feeder fee but are not edge-actuatable
- **Design notes:** footprint `easyeda:SW-SMD_2P-TS24CA` — pads 1/2 are the electrical terminals
  at 3.4 mm land spacing (3.35 ± 0.1 mm terminals per drawing), pads 3/4 are mechanical frame
  tabs left netless, two Ø0.7 mm locating holes at 1.7 mm pitch. **Not suitable for `SW4`** (the
  master power switch): momentary, and 50 mA is marginal for the logic tree — SW4 stays open.
- **Datasheet:** pcb/datasheets/C393942-TS24CA.pdf — 50 mA/12 VDC contact rating vs µA-scale
  reset/GPIO switching: fine; contact resistance ≤ 100 mΩ; single-pole single-loop matches the
  2-pin `Switch:SW_Push` symbol; bounce ≤ 10 ms (debounced by C9/C19/C24 networks already present)

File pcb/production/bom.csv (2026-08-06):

Designator | Footprint | Quantity | Value | LCSC Part #
C1, C10, C16, C17, C19, C2, C20, C21, C22, C24, C27, C28, C3, C31, C32, C33, C4, C45, C47, C5, C9 | 0402 | 21 | 100nF | C1525
C11, C12 | 0402 | 2 | 20pF | C1554
C13, C14 | 0402 | 2 | 10pF | C32949
C15, C41 | 0402 | 2 | 2.2nF | C1531
C18, C34, C35, C36, C8 | 0402 | 5 | 10nF | C15195
C23, C46, C6 | 0402 | 3 | 4.7uF | C307423
C25, C26, C29, C30, C43, C44 | 0402 | 6 | 12pF | C1547
C37, C7 | 0402 | 2 | 1uF | C52923
C38 | 0402 | 1 | 33nF | C106862
C39 | 0402 | 1 | 1.5pF | C1552
C40 | 0402 | 1 | 1pF | C1550
C42 | 0402 | 1 | 4.7nF | C1538
C48 | 1206 | 1 | 0.22uF | C1857
C49 | 1206 | 1 | 10uF | C13585
C50, C51 | 1206 | 2 | 10uF | C7171
D1, D10, D2 | D_SOD-123 | 3 | B5819W | C64885
D11, D12, D14, D18 | 0603 | 4 | VERDE | C12624
D13, D15 | 0603 | 2 | ROJO | C2286
D16 | 0603 | 1 | AZUL | C2288
D3 | SOT-23-6_L2.9-W1.6-P0.95-LS2.9-BL | 1 | SRV05-4A_C20615829 | C20615829
FB1, FB2 | 0805 | 2 | 120R@100MHz | C79382
INT, RATM, RSTM32 | SW-SMD_L3.9-W3.0-P4.45 | 3 | TS-1088-AR02016_C720477 | C720477
J1 | PinHeader_1x04_P2.54mm_Vertical | 1 | SWD | C2691448
J10 | PinHeader_2x04_P2.54mm_Vertical | 1 | CONN_MANDO | C492421
J11 | OLED | 1 | OLED | C2691448
J12 | PinHeader_1x06_P2.54mm_Vertical | 1 | STM32 SPI | C492405
J13 | PinHeader_1x04_P2.54mm_Vertical | 1 | STM32 I2C | C2691448
J14 | PinHeader_1x04_P2.54mm_Horizontal | 1 | STM32 USART | C2691448
J15 | PinHeader_2x03_P2.54mm_Vertical | 1 | ICSP | C492420
J16, J3 | MICRO-USB-SMD_MICROXNJ_1 | 2 | USB_B_Micro | C404969
J17 | SMA_142-0701-201 | 1 | Conn_Coaxial | C496551
J2 | PinHeader_1x03_P2.54mm_Vertical | 1 | Jumper | C2937625
J4 | PinHeader_1x03_P2.54mm_Vertical | 1 | CONN_MOT_1 | C2937625
J5 | PinHeader_1x03_P2.54mm_Vertical | 1 | CONN_MOT_2 | C2937625
J6 | PinHeader_1x03_P2.54mm_Vertical | 1 | CONN_MOT_3 | C2937625
J7 | PinHeader_1x03_P2.54mm_Vertical | 1 | CONN_MOT_4 | C2937625
J8 | AMASS_XT60-M | 1 | XT-60 | C98733
J9 | PinHeader_1x06_P2.54mm_Horizontal | 1 | LIDAR | C492405
L1 | 0402 | 1 | 600R@100MHz | C76884
L2 | 0402 | 1 | 8.2nH | C98003
L3 | 0402 | 1 | 3.9nH | C14033
L4 | 0402 | 1 | 2.7nH | C27123
R1, R10, R2, R21, R3, R30, R33, R35, R36 | 0402 | 9 | 10K | C25744
R17 | 0402 | 1 | 47k | C25792
R18 | 0402 | 1 | 15k | C25756
R19, R20, R38, R7, R8, R9 | 0402 | 6 | 4.7k | C25900
R22 | 0402 | 1 | 330 | C25104
R23, R28, R32 | 0603 | 3 | 1k | C21190
R24, R25, R5, R6 | 0603 | 4 | 22 | C25092
R26, R27 | 0402 | 2 | 1k | C11702
R29, R31 | 0603 | 2 | 1.5k | C22843
R34 | 0603 | 1 | 470 | C23179
R37 | 0402 | 1 | 1M | C26083
R39 | 0603 | 1 | 100 | C25076
R4 | 0402 | 1 | 1.5K | C25867
SW4 | SW-TH_K3-1204D | 1 | K3-1204D_C145861 | C145861
U1 | LQFP-64_10x10mm_P0.5mm | 1 | STM32F103R8T6 | C46034
U10 | TO-220-3_Horizontal_TabDown | 1 | LM7805_TO220 | C5189702
U11 | SOT-223-3_TabPin2 | 1 | AMS1117-3.3 | C6186
U2 | InvenSense_QFN-24_4x4mm_P0.5mm | 1 | MPU-6050 | C24112
U3 | TQFP-32_7x7mm_P0.8mm | 1 | ATMEGA328P-AU | C14877
U4 | SOIC-16_3.9x9.9mm_P1.27mm | 1 | CH340G | C14267
U5 | SOIC-8_3.9x4.9mm_P1.27mm | 1 | LM358DR | C5423
U6 | SOIC-20W_7.5x12.8mm_P1.27mm | 1 | 74HC245 | C10093
U7 | QFN-20-1EP_4x4mm_P0.5mm_EP2.5x2.5mm | 1 | nRF24L01P | C8791
U8 | TF-SMD_472192001 | 1 | MICROSD_C164170 | C164170
U9 | SOT-353_SC-70-5 | 1 | 74AHC1G125 | C151890
Y1 | Crystal_SMD_5032-2Pin_5.0x3.2mm | 1 | 8MHz | C115962
Y2 | Crystal_SMD_3215-2Pin_3.2x1.5mm | 1 | 32.768KHz | C32346
Y3, Y5 | Crystal_SMD_SeikoEpson_TSX3225-4Pin_3.2x2.5mm | 2 | 16MHz | C13738
Y4 | Crystal_SMD_SeikoEpson_TSX3225-4Pin_3.2x2.5mm | 1 | 12MHz | C9002

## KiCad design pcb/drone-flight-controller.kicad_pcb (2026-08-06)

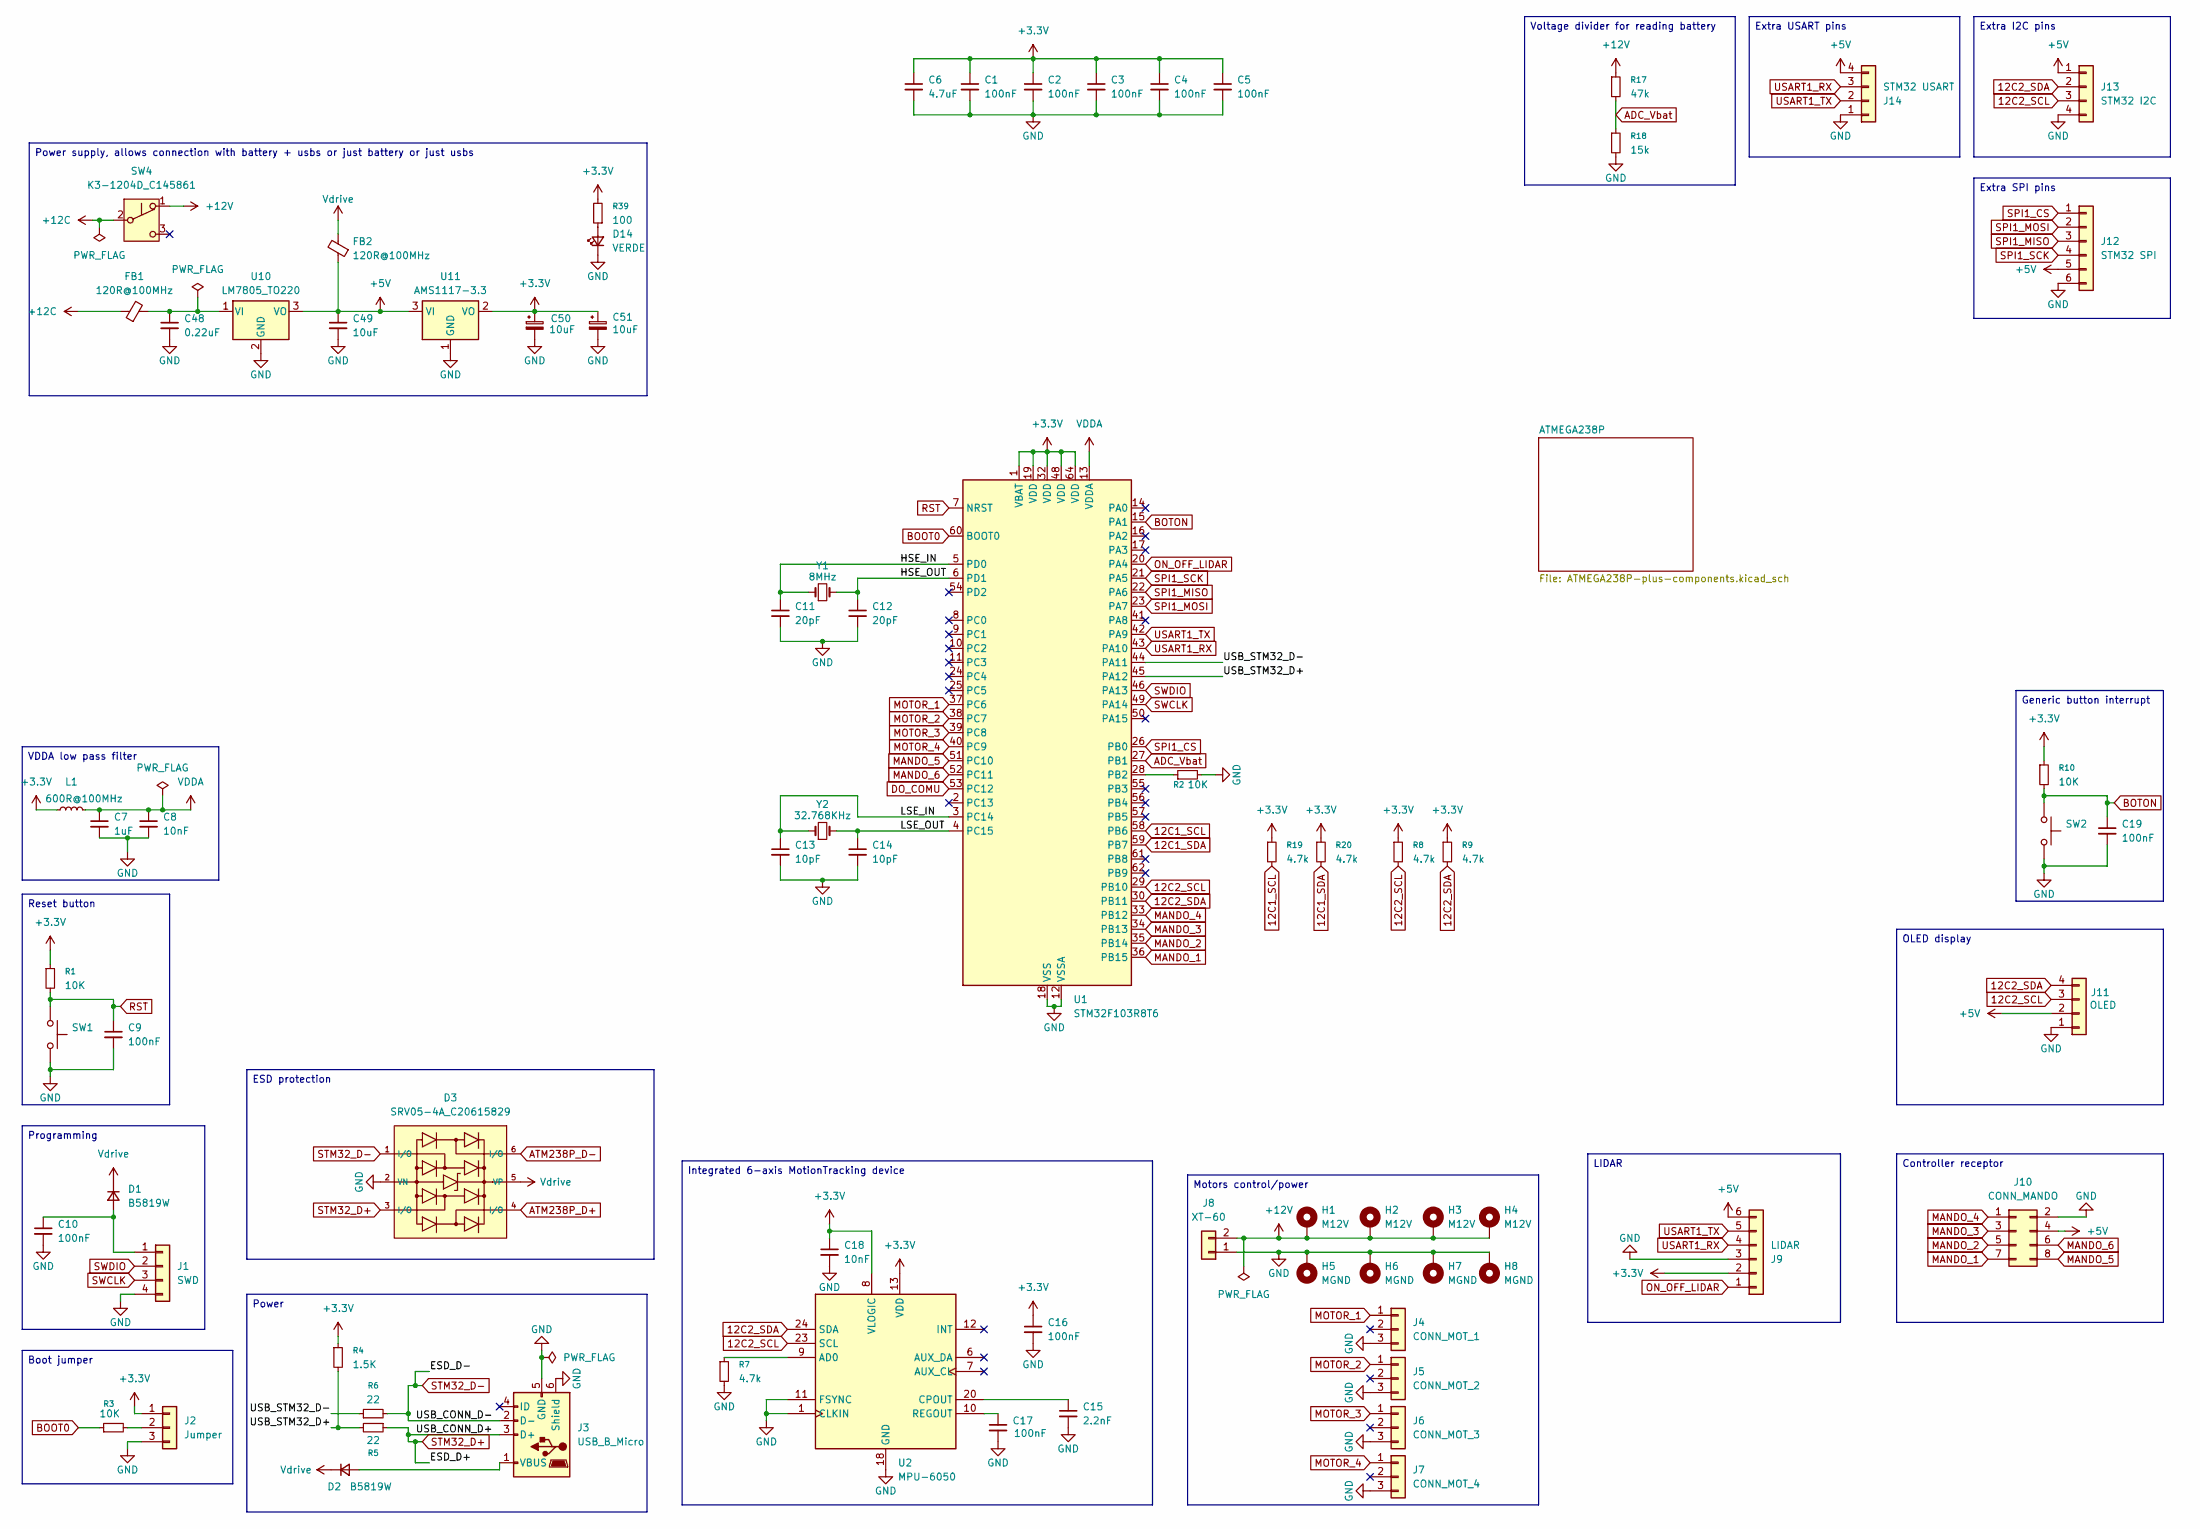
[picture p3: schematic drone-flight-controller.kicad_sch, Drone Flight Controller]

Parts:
C1, C2, C3, C4, C5, C9, C10, C16, C17, C19: 100nF; C_0402_1005Metric; Part CL05B104KO5NNNC; LCSC C1525
C6: 4.7uF; C_0402_1005Metric; Part CL05A475MQ5NRNC; LCSC C307423
C7: 1uF; C_0402_1005Metric; Part CL05A105KA5NQNC; LCSC C52923
C8, C18: 10nF; C_0402_1005Metric; Part CL05B103KB5NNNC; LCSC C15195
C11, C12: 20pF; C_0402_1005Metric; Part 0402CG200J500NT; LCSC C1554
C13, C14: 10pF; C_0402_1005Metric; Part CL05C100JB5NNNC; LCSC C32949
C15: 2.2nF; C_0402_1005Metric; Part 0402B222K500NT; LCSC C1531
C48: 0.22uF; C_1206_3216Metric; Part 1206B224K500NT; LCSC C1857
C49: 10uF; C_1206_3216Metric; Part CL31A106KBHNNNE; LCSC C13585
C50, C51: 10uF; C_1206_3216Metric; Part TAJA106K016RNJ; LCSC C7171
D1, D2: B5819W; D_SOD-123; Part B5819W; LCSC C64885
D3: SRV05-4A_C20615829; SOT-23-6_L2.9-W1.6-P0.95-LS2.9-BL; Part SRV05-4A; LCSC C20615829
D14: VERDE; LED_0603_1608Metric; Part KT-0603G; LCSC C12624
FB1, FB2: 120R@100MHz; L_0805_2012Metric; Part BLM21PG121SN1D; LCSC C79382
H1, H2, H3, H4: M12V; MountingHole_3.5mm_5.5mm
H5, H6, H7, H8: MGND; MountingHole_3.5mm_5.5mm
J1: SWD; PinHeader_1x04_P2.54mm_Vertical; Part PZ254V-11-04P; LCSC C2691448
J2: Jumper; PinHeader_1x03_P2.54mm_Vertical; Part PZ254V-11-03P; LCSC C2937625
J3: USB_B_Micro; MICRO-USB-SMD_MICROXNJ_1; Part MicroXNJ; LCSC C404969
J4: CONN_MOT_1; PinHeader_1x03_P2.54mm_Vertical; Part PZ254V-11-03P; LCSC C2937625
J5: CONN_MOT_2; PinHeader_1x03_P2.54mm_Vertical; Part PZ254V-11-03P; LCSC C2937625
J6: CONN_MOT_3; PinHeader_1x03_P2.54mm_Vertical; Part PZ254V-11-03P; LCSC C2937625
J7: CONN_MOT_4; PinHeader_1x03_P2.54mm_Vertical; Part PZ254V-11-03P; LCSC C2937625
J8: XT-60; AMASS_XT60-M; Part XT60-M.; LCSC C98733
J9: LIDAR; PinHeader_1x06_P2.54mm_Horizontal; Part PZ254V-11-06P; LCSC C492405
J10: CONN_MANDO; PinHeader_2x04_P2.54mm_Vertical; Part PZ254V-12-8P; LCSC C492421
J11: OLED; Part PZ254V-11-04P; LCSC C2691448
J12: STM32 SPI; PinHeader_1x06_P2.54mm_Vertical; Part PZ254V-11-06P; LCSC C492405
J13: STM32 I2C; PinHeader_1x04_P2.54mm_Vertical; Part PZ254V-11-04P; LCSC C2691448
J14: STM32 USART; PinHeader_1x04_P2.54mm_Horizontal; Part PZ254V-11-04P; LCSC C2691448
L1: 600R@100MHz; L_0402_1005Metric; Part BLM15AG601SN1D; LCSC C76884
R1, R2, R3, R10: 10K; R_0402_1005Metric; Part 0402WGF1002TCE; LCSC C25744
R4: 1.5K; R_0402_1005Metric; Part 0402WGF1501TCE; LCSC C25867
R5, R6: 22; R_0603_1608Metric; Part 0402WGF220JTCE; LCSC C25092
R7, R8, R9, R19, R20: 4.7k; R_0402_1005Metric; Part 0402WGF4701TCE; LCSC C25900
R17: 47k; R_0402_1005Metric; Part 0402WGF4702TCE; LCSC C25792
R18: 15k; R_0402_1005Metric; Part 0402WGF1502TCE; LCSC C25756
R39: 100; R_0603_1608Metric; Part 0402WGF1000TCE; LCSC C25076
SW1, SW2: TS-1088-AR02016_C720477; SW-SMD_L3.9-W3.0-P4.45; Part TS-1088-AR02016; LCSC C720477
SW4: K3-1204D_C145861; SW-TH_K3-1204D; Part K3-1204D; LCSC C145861
U1: STM32F103R8T6; LQFP-64_10x10mm_P0.5mm; Part STM32F103R8T6; LCSC C46034
U2: MPU-6050; InvenSense_QFN-24_4x4mm_P0.5mm; Part MPU-6050; LCSC C24112
U10: LM7805_TO220; TO-220-3_Horizontal_TabDown; Part L7805CV; LCSC C5189702
U11: AMS1117-3.3; SOT-223-3_TabPin2; Part AMS1117-3.3; LCSC C6186
Y1: 8MHz; Crystal_SMD_5032-2Pin_5.0x3.2mm; Part X50328MSB2GI; LCSC C115962
Y2: 32.768KHz; Crystal_SMD_3215-2Pin_3.2x1.5mm; Part Q13FC13500004; LCSC C32346

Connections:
12C1_SCL: R19.2, U1.58 (PB6); also elsewhere on the board
12C1_SDA: R20.2, U1.59 (PB7); also elsewhere on the board
12C2_SCL: J11.3, J13.3, R8.2, U1.29 (PB10), U2.23 (SCL)
12C2_SDA: J11.4, J13.2, R9.2, U1.30 (PB11), U2.24 (SDA)
+3.3V: C1.1, C2.1, C3.1, C4.1, C5.1, C6.1, C16.1, C18.1, C50.1, C51.1, J2.1, J9.2, L1.1, R1.1, R4.1, R8.1, R9.1, R10.1, R19.1, R20.1, R39.2, U1.1 (VBAT), U1.19 (VDD), U1.32 (VDD), U1.48 (VDD), U1.64 (VDD), U2.8 (VLOGIC), U2.13 (VDD), U11.2 (VO); also elsewhere on the board
+5V: C49.1, FB2.1, J9.6, J10.4, J11.2, J12.5, J13.1, J14.4, U10.3 (VO), U11.3 (VI); also elsewhere on the board
+12C: FB1.1, SW4.2 (B)
+12V: H1.1 (1_1), H2.1 (1_1), H3.1 (1_1), H4.1 (1_1), J8.2, R17.1, SW4.1 (A)
/HSE_IN: C11.1, U1.5 (PD0), Y1.1
/HSE_OUT: C12.1, U1.6 (PD1), Y1.2
/LSE_IN: C13.1, U1.3 (PC14), Y2.1
/LSE_OUT: C14.1, U1.4 (PC15), Y2.2
/USB_STM32_D+: R4.2, R5.2, U1.45 (PA12)
/USB_STM32_D-: R6.1, U1.44 (PA11)
ADC_Vbat: R17.2, R18.1, U1.27 (PB1)
ATM238P_D+: D3.4 (I/O); also elsewhere on the board
ATM238P_D-: D3.6 (I/O); also elsewhere on the board
BOOT0: R3.1, U1.60 (BOOT0)
BOTON: C19.1, R10.2, SW2.1, U1.15 (PA1); also elsewhere on the board
DO_COMU: U1.53 (PC12); also elsewhere on the board
GND: C1.2, C2.2, C3.2, C4.2, C5.2, C6.2, C7.2, C8.2, C9.2, C10.2, C11.2, C12.2, C13.2, C14.2, C15.2, C16.2, C17.2, C18.2, C19.2, C48.2, C49.2, C50.2, C51.2, D3.2 (VN), D14.1 (K), H5.1 (1_1), H6.1 (1_1), H7.1 (1_1), H8.1 (1_1), J1.4, J2.3, J3.5 (GND), J3.6 (Shield), J4.3, J5.3, J6.3, J7.3, J8.1, J9.3, J10.2, J11.1, J12.6, J13.4, J14.1, R2.2, R7.2, R18.2, SW1.2, SW2.2, U1.12 (VSSA), U1.18 (VSS), U1.31 (VSS), U1.47 (VSS), U1.63 (VSS), U2.1 (CLKIN), U2.11 (FSYNC), U2.18 (GND), U10.2 (GND), U11.1 (GND); also elsewhere on the board
MANDO_1: J10.7, U1.36 (PB15)
MANDO_2: J10.5, U1.35 (PB14)
MANDO_3: J10.3, U1.34 (PB13)
MANDO_4: J10.1, U1.33 (PB12)
MANDO_5: J10.8, U1.51 (PC10)
MANDO_6: J10.6, U1.52 (PC11)
MOTOR_1: J4.1, U1.37 (PC6)
MOTOR_2: J5.1, U1.38 (PC7)
MOTOR_3: J6.1, U1.39 (PC8)
MOTOR_4: J7.1, U1.40 (PC9)
unnamed: C10.1, D1.2 (A), J1.1
unnamed: D2.2 (A), J3.1 (VBUS)
unnamed: D14.2 (A), R39.1
unnamed: J2.2, R3.2
unnamed: R2.1, U1.28 (PB2)
unnamed: R7.1, U2.9 (AD0)
unnamed: C15.1, U2.20 (CPOUT)
unnamed: C17.1, U2.10 (REGOUT)
unnamed: C48.1, FB1.2, U10.1 (VI)
ON_OFF_LIDAR: J9.1, U1.20 (PA4)
RST: C9.1, R1.2, SW1.1, U1.7 (NRST); also elsewhere on the board
SPI1_CS: J12.1, U1.26 (PB0)
SPI1_MISO: J12.3, U1.22 (PA6)
SPI1_MOSI: J12.2, U1.23 (PA7)
SPI1_SCK: J12.4, U1.21 (PA5)
STM32_D+: D3.3 (I/O), J3.3 (D+), R5.1
STM32_D-: D3.1 (I/O), J3.2 (D-), R6.2
SWCLK: J1.3, U1.49 (PA14)
SWDIO: J1.2, U1.46 (PA13)
USART1_RX: J9.4, J14.3, U1.43 (PA10)
USART1_TX: J9.5, J14.2, U1.42 (PA9)
VDDA: C7.1, C8.1, L1.2, U1.13 (VDDA)
Vdrive: D1.1 (K), D2.1 (K), D3.5 (VP), FB2.2; also elsewhere on the board

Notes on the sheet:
Voltage divider for reading battery
Extra I2C pins
OLED display
Controller receptor
LIDAR
Motors control/power
Extra SPI pins
Power
Programming
Power supply, allows connection with battery + usbs or just battery or just usbs
Integrated 6-axis MotionTracking device
Extra USART pins
ESD protection
Boot jumper
VDDA low pass filter
Reset button
Generic button interrupt

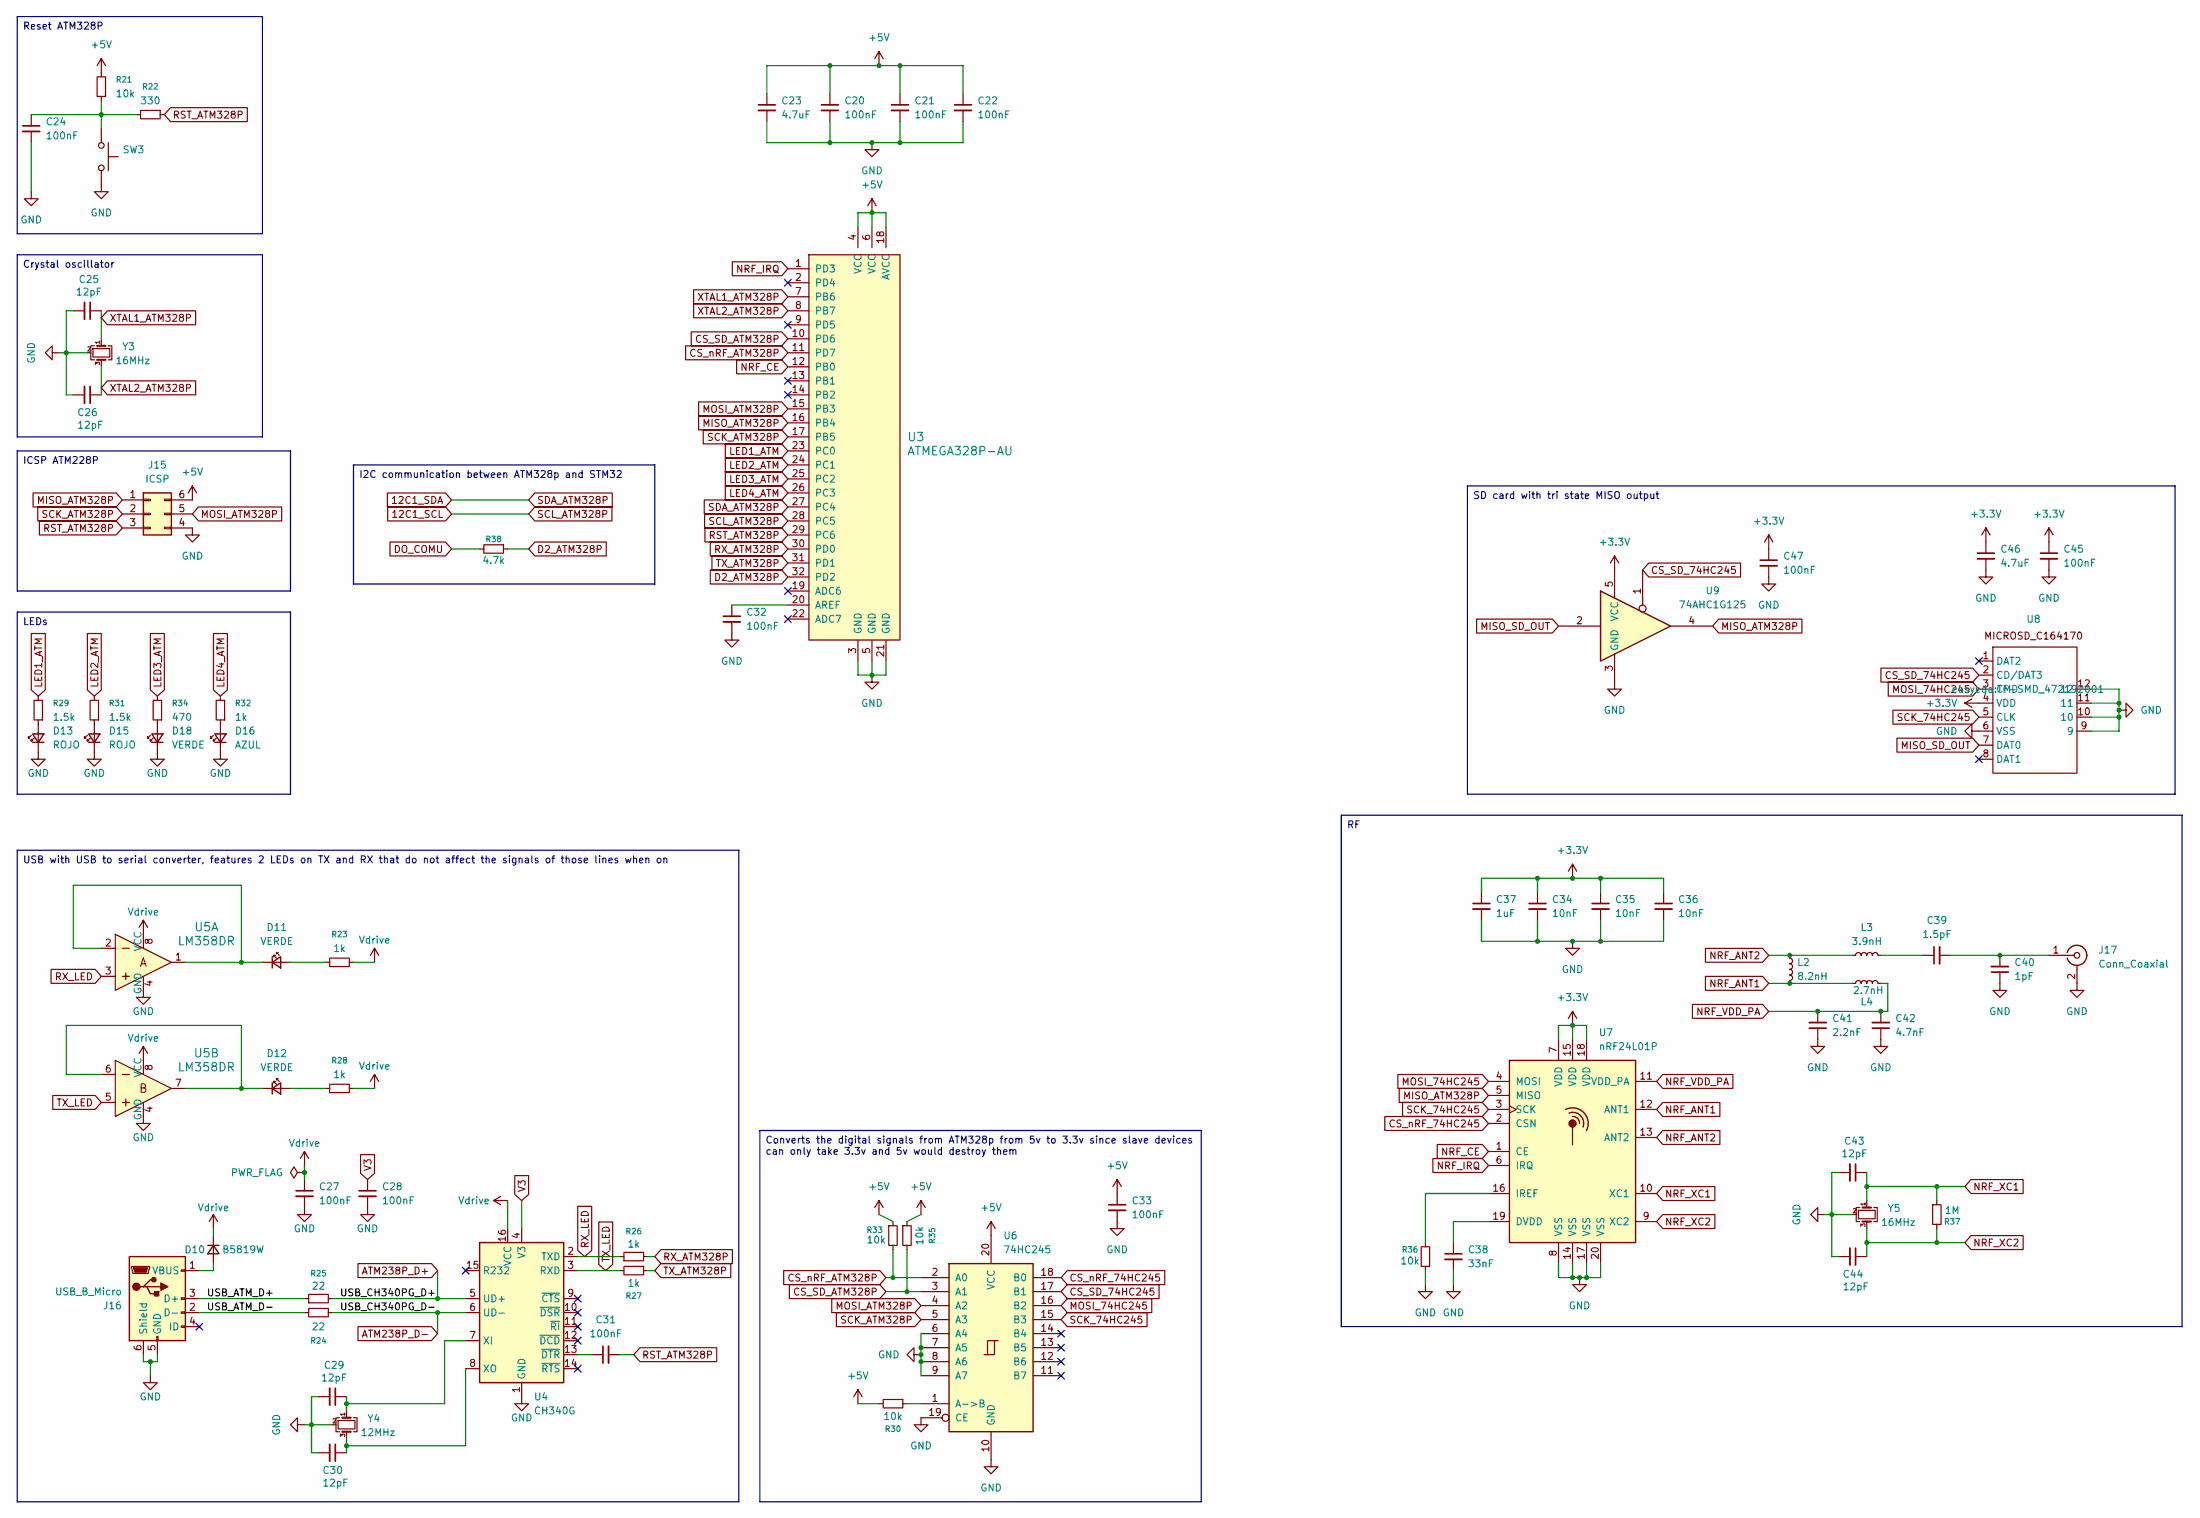
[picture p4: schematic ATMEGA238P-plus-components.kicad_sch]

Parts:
C20, C21, C22, C24, C27, C28, C31, C32, C33, C45, C47: 100nF; C_0402_1005Metric; Part CL05B104KO5NNNC; LCSC C1525
C23, C46: 4.7uF; C_0402_1005Metric; Part CL05A475MQ5NRNC; LCSC C307423
C25, C26, C29, C30, C43, C44: 12pF; C_0402_1005Metric; Part 0402CG120J500NT; LCSC C1547
C34, C35, C36: 10nF; C_0402_1005Metric; Part CL05B103KB5NNNC; LCSC C15195
C37: 1uF; C_0402_1005Metric; Part CL05A105KA5NQNC; LCSC C52923
C38: 33nF; C_0402_1005Metric; Part CC0402KRX7R9BB333; LCSC C106862
C39: 1.5pF; C_0402_1005Metric; Part 0402CG1R5C500NT; LCSC C1552
C40: 1pF; C_0402_1005Metric; Part 0402CG1R0C500NT; LCSC C1550
C41: 2.2nF; C_0402_1005Metric; Part 0402B222K500NT; LCSC C1531
C42: 4.7nF; C_0402_1005Metric; Part 0402B472K500NT; LCSC C1538
D10: B5819W; D_SOD-123; Part B5819W; LCSC C64885
D11, D12, D18: VERDE; LED_0603_1608Metric; Part KT-0603G; LCSC C12624
D13, D15: ROJO; LED_0603_1608Metric; Part KT-0603R; LCSC C2286
D16: AZUL; LED_0603_1608Metric; Part KT-0603B; LCSC C2288
J15: ICSP; PinHeader_2x03_P2.54mm_Vertical; Part PZ254V-12-6P; LCSC C492420
J16: USB_B_Micro; MICRO-USB-SMD_MICROXNJ_1; Part MicroXNJ; LCSC C404969
J17: Conn_Coaxial; SMA_142-0701-201; Part BWSMA-KWE-Z001; LCSC C496551
L2: 8.2nH; L_0402_1005Metric; Part LQG15HS8N2J02D; LCSC C98003
L3: 3.9nH; L_0402_1005Metric; Part SDCL1005C3N9STDF; LCSC C14033
L4: 2.7nH; L_0402_1005Metric; Part SDCL1005C2N7STDF; LCSC C27123
R21, R30, R33, R35, R36: 10k; R_0402_1005Metric; Part 0402WGF1002TCE; LCSC C25744
R22: 330; R_0402_1005Metric; Part 0402WGF3300TCE; LCSC C25104
R23, R28, R32: 1k; R_0603_1608Metric; Part 0603WAF1001T5E; LCSC C21190
R24, R25: 22; R_0603_1608Metric; Part 0402WGF220JTCE; LCSC C25092
R26, R27: 1k; R_0402_1005Metric; Part 0402WGF1001TCE; LCSC C11702
R29, R31: 1.5k; R_0603_1608Metric; Part 0603WAF1501T5E; LCSC C22843
R34: 470; R_0603_1608Metric; Part 0603WAF4700T5E; LCSC C23179
R37: 1M; R_0402_1005Metric; Part 0402WGF1004TCE; LCSC C26083
R38: 4.7k; R_0402_1005Metric; Part 0402WGF4701TCE; LCSC C25900
SW3: TS-1088-AR02016_C720477; SW-SMD_L3.9-W3.0-P4.45; Part TS-1088-AR02016; LCSC C720477
U3: ATMEGA328P-AU; TQFP-32_7x7mm_P0.8mm; MPN ATMEGA328P-AU; Digi-Key_PN ATMEGA328P-AU-ND
U4: CH340G; SOIC-16_3.9x9.9mm_P1.27mm; Part CH340G; LCSC C14267
U5: LM358DR; SOIC-8_3.9x4.9mm_P1.27mm; MPN LM358DR; Digi-Key_PN 296-1014-1-ND
U6: 74HC245; SOIC-20W_7.5x12.8mm_P1.27mm; Part SN74HC245DWR; LCSC C10093
U7: nRF24L01P; QFN-20-1EP_4x4mm_P0.5mm_EP2.5x2.5mm; Part NRF24L01P-R; LCSC C8791
U8: MICROSD_C164170; TF-SMD_472192001; Part 472192001; LCSC C164170
U9: 74AHC1G125; SOT-353_SC-70-5; Part SN74AHC1G125DCKR; LCSC C151890
Y3, Y5: 16MHz; Crystal_SMD_SeikoEpson_TSX3225-4Pin_3.2x2.5mm; Part X322516MLB4SI; LCSC C13738
Y4: 12MHz; Crystal_SMD_SeikoEpson_TSX3225-4Pin_3.2x2.5mm; Part X322512MSB4SI; LCSC C9002

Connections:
12C1_SCL: U3.28 (PC5); also elsewhere on the board
12C1_SDA: U3.27 (PC4); also elsewhere on the board
+3.3V: C34.1, C35.1, C36.1, C37.1, C45.1, C46.1, C47.1, U7.7 (VDD), U7.15 (VDD), U7.18 (VDD), U8.4 (VDD), U9.5 (VCC); also elsewhere on the board
+5V: C20.1, C21.1, C22.1, C23.1, C33.1, J15.6, R21.2, R30.2, R33.1, R35.1, U3.4 (VCC), U3.6 (VCC), U3.18 (AVCC), U6.20 (VCC); also elsewhere on the board
/ATMEGA238P/USB_ATM_D+: J16.3 (D+), R25.1
/ATMEGA238P/USB_ATM_D-: J16.2 (D-), R24.2
ATM238P_D+: R25.2, U4.5 (UD+); also elsewhere on the board
ATM238P_D-: R24.1, U4.6 (UD-); also elsewhere on the board
CS_SD_74HC245: U6.17 (B1), U8.2 (CD/DAT3), U9.1
CS_SD_ATM328P: R35.2, U3.10 (PD6), U6.3 (A1)
CS_nRF_74HC245: U6.18 (B0), U7.2 (CSN)
CS_nRF_ATM328P: R33.2, U3.11 (PD7), U6.2 (A0)
D2_ATM328P: R38.1, U3.32 (PD2)
DO_COMU: R38.2; also elsewhere on the board
GND: C20.2, C21.2, C22.2, C23.2, C24.2, C25.2, C26.2, C27.2, C28.2, C29.2, C30.2, C32.2, C33.2, C34.2, C35.2, C36.2, C37.2, C38.2, C40.1, C41.1, C42.1, C43.2, C44.2, C45.2, C46.2, C47.2, D13.1 (K), D15.1 (K), D16.1 (K), D18.1 (K), J15.4, J16.5 (GND), J16.6 (Shield), J17.2 (Ext), R36.1, SW3.2, U3.3 (GND), U3.5 (GND), U3.21 (GND), U4.1 (GND), U5.4 (GND), U6.6 (A4), U6.7 (A5), U6.8 (A6), U6.9 (A7), U6.10 (GND), U6.19 (CE), U7.8 (VSS), U7.14 (VSS), U7.17 (VSS), U7.20 (VSS), U8.6 (VSS), U8.9, U8.10, U8.11, U8.12, U9.3 (GND), Y3.2 (G), Y3.4 (G), Y4.2 (G), Y4.4 (G), Y5.2 (G), Y5.4 (G); also elsewhere on the board
LED1_ATM: R29.2, U3.23 (PC0)
LED2_ATM: R31.2, U3.24 (PC1)
LED3_ATM: R34.2, U3.25 (PC2)
LED4_ATM: R32.2, U3.26 (PC3)
MISO_ATM328P: J15.1, U3.16 (PB4), U7.5 (MISO), U9.4
MISO_SD_OUT: U8.7 (DAT0), U9.2
MOSI_74HC245: U6.16 (B2), U7.4 (MOSI), U8.3 (CMD)
MOSI_ATM328P: J15.5, U3.15 (PB3), U6.4 (A2)
NRF_ANT1: L2.2, L4.1, U7.12 (ANT1)
NRF_ANT2: L2.1, L3.1, U7.13 (ANT2)
NRF_CE: U3.12 (PB0), U7.1 (CE)
NRF_IRQ: U3.1 (PD3), U7.6 (IRQ)
NRF_VDD_PA: C41.2, C42.2, L4.2, U7.11 (VDD_PA)
NRF_XC1: C43.1, R37.1, U7.10 (XC1), Y5.1
NRF_XC2: C44.1, R37.2, U7.9 (XC2), Y5.3
unnamed 53: C24.1, R21.1, R22.2, SW3.1; also elsewhere on the board
unnamed: C39.1, L3.2
unnamed: D10.2 (A), J16.1 (VBUS)
unnamed: D11.2 (A), R23.1
unnamed: D11.1 (K), U5.1, U5.2
unnamed: D12.2 (A), R28.1
unnamed: D12.1 (K), U5.6, U5.7
unnamed: D13.2 (A), R29.1
unnamed: D15.2 (A), R31.1
unnamed: D16.2 (A), R32.1
unnamed: D18.2 (A), R34.1
unnamed: C39.2, C40.2, J17.1 (In)
unnamed: C32.1, U3.20 (AREF)
unnamed: C29.1, U4.7 (XI), Y4.1
unnamed: C30.1, U4.8 (XO), Y4.3
unnamed: C31.1, U4.13 (~DTR)
unnamed: R30.1, U6.1 (A->B)
unnamed: C38.1, U7.19 (DVDD)
unnamed: R36.2, U7.16 (IREF)
RST_ATM328P: C31.2, J15.3, R22.1, U3.29 (PC6)
RX_ATM328P: R26.2, U3.30 (PD0)
RX_LED: R26.1, U4.2 (TXD), U5.3
SCK_74HC245: U6.15 (B3), U7.3 (SCK), U8.5 (CLK)
SCK_ATM328P: J15.2, U3.17 (PB5), U6.5 (A3)
TX_ATM328P: R27.1, U3.31 (PD1)
TX_LED: R27.2, U4.3 (RXD), U5.5
V3: C28.1, U4.4 (V3)
Vdrive: C27.1, D10.1 (K), R23.2, R28.2, U4.16 (VCC), U5.8 (VCC); also elsewhere on the board
XTAL1_ATM328P: C25.1, U3.7 (PB6), Y3.1
XTAL2_ATM328P: C26.1, U3.8 (PB7), Y3.3

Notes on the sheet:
I2C communication between ATM328p and STM32
LEDs
SD card with tri state MISO output
USB with USB to serial converter, features 2 LEDs on TX and RX that do not affect the signals of those lines when on
Converts the digital signals from ATM328p from 5v to 3.3v since slave devices can only take 3.3v and 5v would destroy them
ICSP ATM228P
Crystal oscillator
Reset ATM328P

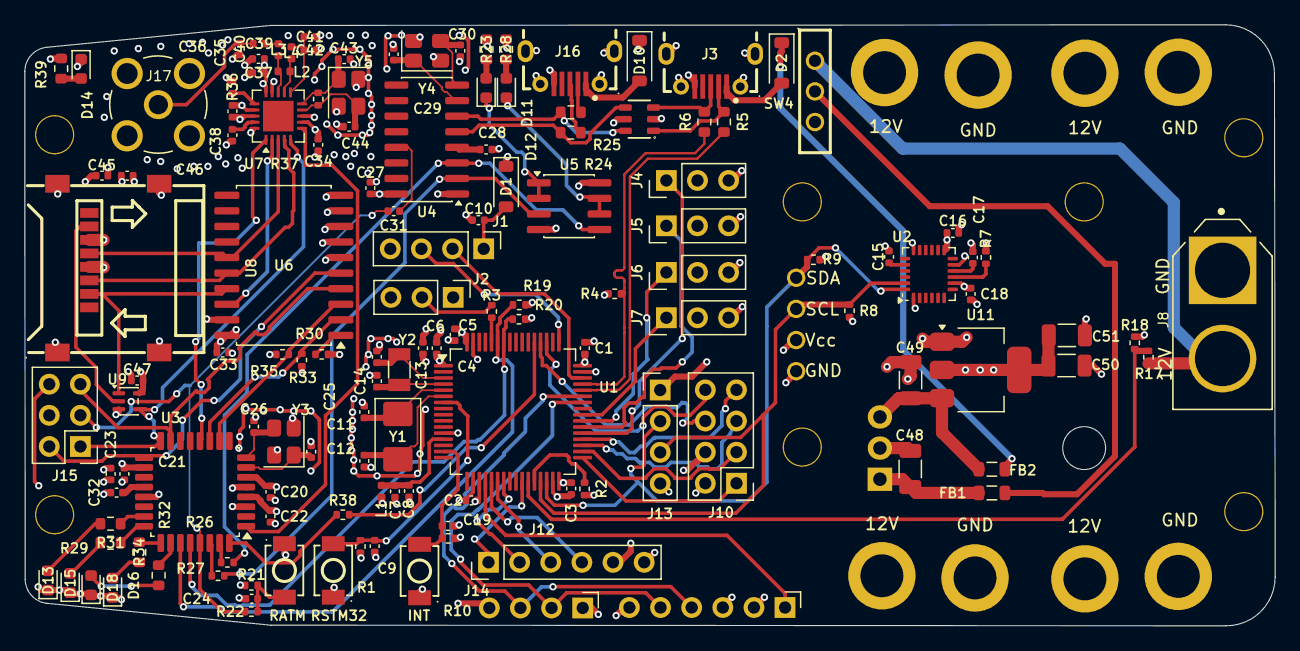
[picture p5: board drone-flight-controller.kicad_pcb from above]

Board: 4 copper layers, 102.0 x 49.0 mm, 146 parts (1 on the bottom side), 105 nets.

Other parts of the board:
INT: TS-1088-AR02016_C720477; SW-SMD_L3.9-W3.0-P4.45
RATM: TS-1088-AR02016_C720477; SW-SMD_L3.9-W3.0-P4.45
RSTM32: TS-1088-AR02016_C720477; SW-SMD_L3.9-W3.0-P4.45

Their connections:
BOTON: INT.1; also elsewhere on the board
GND: INT.2, RATM.2, RSTM32.2; also elsewhere on the board
unnamed 53: RATM.1; also elsewhere on the board
RST: RSTM32.1; also elsewhere on the board

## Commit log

2026-07-13 pcb datasheets
2026-07-13 flight controller schematics, stm32 done, continue with telemetry module with atm328p
    [ATMEGA238P-plus-components.kicad_sch, drone-flight-controller.kicad_pcb, drone-flight-controller.kicad_sch]
2026-07-14 added sd card, RF module and power supply
    [ATMEGA238P-plus-components.kicad_sch, drone-flight-controller.kicad_sch]
2026-07-17 pcb: track project library tables
    The easyeda footprint library registration lives in fp-lib-table; without
    it the custom microSD footprint cannot resolve on a fresh clone.
2026-07-17 docs: sync all docs with the finished schematic capture
    Every doc still described the 2026-07-11 'early MCU fragment' state.
    Refresh them to the actual design — STM32 core with full power tree plus
    the ATmega328P telemetry subsheet — and record the remaining open items
    (microSD pin types, L1 value, PWR_FLAGs, footprints/MPNs, empty PCB) so
    nothing overstates readiness.
2026-07-17 pcb: correct microSD symbol pin electrical types
    All twelve pins were typed 'input', which broke ERC's direction checks
    (MISO ended up as two undriven inputs) and misdeclared the supply pins.
    Now VDD/VSS are power_in, DAT0 output, CMD/DAT bidirectional, CLK input,
    and the shell tabs passive — in the library and the schematic's embedded
    symbol cache.
    [ATMEGA238P-plus-components.kicad_sch]
2026-07-17 docs: drop the resolved microSD pin-type blocker
    The symbol's pin electrical types were fixed, so the docs' open items
    shrink to L1, PWR_FLAGs, footprint/MPN coverage, ERC, and the layout.
2026-07-19 pcb: source the tact switches as SHOU HAN TS24CA (C393942)
    Give SW1 (STM32 reset), SW2 (user button), and SW3 (ATmega reset) a real
    orderable part: footprint, LCSC/MPN fields, and datasheet, so they stop
    blocking BOM/footprint coverage. One part number covers all three buttons;
    side actuation keeps them reachable from the board edge. SW4 is deliberately
    untouched — it is the master power switch and needs a latching, adequately
    rated part, tracked in DESIGN_REVIEW and the new parts log.
    [ATMEGA238P-plus-components.kicad_sch, drone-flight-controller.kicad_sch]
2026-07-19 footprint assignments
    [ATMEGA238P-plus-components.kicad_sch, drone-flight-controller.kicad_sch]
2026-07-19 erc: first clean native run, plus full footprint assignment
    Fix the CH340G VCC/V3 cross-wiring (the chip was unpowered and its
    internal 3.3 V node sat on the 5 V rail), add PWR_FLAGs to the
    passive-fed rails and GND, no-connect SW4's unused throw, and retype
    the USB shell grounds to passive - ERC now reports 0/0 on both sheets.
    Assign footprints to every remaining component and import all 158 into
    the board so layout can start. Two known netlist gaps recorded in
    DESIGN_REVIEW: the USB shield pads (symbol SH vs footprint 6) and the
    nRF24 exposed pad are floating; MPN coverage is still four parts.
    [ATMEGA238P-plus-components.kicad_sch, drone-flight-controller.kicad_pcb, drone-flight-controller.kicad_sch]
2026-07-19 pcb: ground the USB shields; leave the nRF24 EP per datasheet
    The Update-PCB import exposed that J3/J16's shield pin was numbered SH
    while the footprint's shell pads are numbered 6, and the pin was not
    wired to anything - both connector shells would have floated. Renumber
    the pin to 6 (KiCad's own USB symbol convention) and tie it to GND.
    U7's exposed pad is deliberately left unconnected: the nRF24L01+
    Product Specification v1.0 (p. 65) recommends keeping the die attach
    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
    [ATMEGA238P-plus-components.kicad_sch, drone-flight-controller.kicad_sch]
2026-07-19 pcb: carry the grounded USB shields onto the board
    Update-PCB run after the shield fix: both micro-USB connectors' shell
    pads now sit on GND (pin 6/Shield), import finished with 0 errors and
    only the known-benign warnings (TS24CA mechanical tabs, nRF24 exposed
    pad left unconnected per its datasheet).
    [drone-flight-controller.kicad_pcb]
2026-07-19 sch: canonicalize the two added GND symbols
    KiCad 10 crashed with a zero-byte write every time the root sheet was
    saved. The GND symbols added for the USB shields carried placeholder
    instance data - project "project" with path "/" instead of the real
    project name and sheet UUIDs - plus a missing pin record. KiCad loads
    that fine but its serializer dereferences the sheet path on save and
    died mid-write (truncate-then-crash, hence the empty files). Rebuilt
    both blocks to match KiCad's own output; KiCad 10 CLI ERC is identical
    before and after.
    [ATMEGA238P-plus-components.kicad_sch, drone-flight-controller.kicad_sch]
2026-07-20 pcb: frame outline placed; sheets resaved by KiCad post-fix
    95mm drone frame template placed on the board, and both schematics
    re-serialized by KiCad 10's own writer after the save-crash fix -
    confirming the canonicalized GND blocks round-trip cleanly.
    [ATMEGA238P-plus-components.kicad_sch, drone-flight-controller.kicad_pcb, drone-flight-controller.kicad_sch]
2026-07-20 pcb: switch SW1-SW3 to the TC-6610 THT tact switch (C7528713)
    Replace the low-profile side-actuated TS24CA with a tall 9mm 6x6 THT
    button that stays reachable on the assembled frame. The 4-pin part has
    internally shorted pin pairs across its 6.5mm axis, so the distinct
    1/2/3/4 pad numbering of the converted EasyEDA footprint would strap
    each net across a shorted pair (STM32 held in reset); use KiCad's
    official SW_PUSH_6mm_H9.5mm instead, whose paired 1,1,2,2 pads encode
    the topology and drop onto the existing 2-pin symbols. Headless KiCad
    10 ERC is identical before and after.
    [ATMEGA238P-plus-components.kicad_sch, drone-flight-controller.kicad_sch]
2026-07-20 pcb: sync the TC-6610 THT switch footprints onto the board
    [drone-flight-controller.kicad_pcb]
2026-07-20 pcb: board work in progress from layout session
    [drone-flight-controller.kicad_pcb]
2026-07-20 pcb: 3D models for U3, U5, J3, J16
    U3 and U5 move from the model-less DigiKey footprints to the official
    KiCad TQFP-32 and SOIC-8 footprints, whose STEP models ship with the
    AppImage. J3/J16's micro-USB footprint had no model, no MPN, and
    unknown provenance - replaced wholesale with the SHOU HAN MicroXNJ
    (C404969): converted footprint with shell legs renumbered to the
    Shield pin 6, STEP model, and BOM fields, verified against its
    datasheet drawing. ERC caught that the LM358 is multi-unit and the
    first edit only touched U5A's footprint field; U5B fixed to match.
    Headless KiCad 10 ERC identical to baseline.
    [ATMEGA238P-plus-components.kicad_sch, drone-flight-controller.kicad_sch]
2026-07-20 pcb: import the new U3/U5/USB footprints onto the board
    [ATMEGA238P-plus-components.kicad_sch, drone-flight-controller.kicad_pcb, drone-flight-controller.kicad_sch]
2026-07-20 pcb: session state - U10 folded on board, pending sch fixes
    [ATMEGA238P-plus-components.kicad_sch, drone-flight-controller.kicad_pcb, drone-flight-controller.kicad_sch]
2026-07-20 pcb: re-apply U3/U5 footprints durably; fix U10 sch/board mismatch and U2 3D path
    A symbol-update-with-reset-fields pass reverted U3 and U5 to the
    model-less DigiKey footprints because the embedded library defaults
    still carried them - re-apply the official footprints on the instances
    AND the embedded lib_symbol defaults so a future reset cannot regress
    them again. Align U10's schematic with the board's folded
    TO-220-3_Horizontal_TabDown (the schematic still said the 4-lead
    variant, which a footprint-replacing import would have restored). Point
    U2's model at the QFN-24 EP2.6x2.6 step that actually ships - the
    Sensor_Motion footprint references an EP2.7x2.6 file that does not
    exist in the 3D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
    [ATMEGA238P-plus-components.kicad_sch, drone-flight-controller.kicad_pcb, drone-flight-controller.kicad_sch]
2026-07-20 pcb: replace U3/U5 board footprints with the official model-bearing ones
    [drone-flight-controller.kicad_pcb]
2026-07-20 pcb: source SW4 as the SS12D10G5 slide switch (C7431054)
    Retire the last named unsourced part: the master power switch becomes
    a real latching SPDT slide rated 2A/125V - about 5x margin over the
    logic tree's draw through the LM7805 branch. The converted footprint's
    middle pad is the SPDT common, matching the existing +12V/+12C wiring
    with no renumbering, and it brings the 3D model the placeholder
    Switch_Slide footprint never had. Headless ERC identical.
    [drone-flight-controller.kicad_sch]
2026-07-20 pcb: import the SS12D10G5 footprint onto the board
    [drone-flight-controller.kicad_pcb]
2026-07-20 pcb: layout session state
    [drone-flight-controller.kicad_pcb, drone-flight-controller.kicad_sch]
2026-07-20 pcb: resolve L1 - VDDA gets a real 600R ferrite bead and datasheet caps
    The VDDA filter's L1 carried the impossible value 27nF since capture.
    It is now a Murata BLM15AG601SN1D 600R@100MHz bead (0402, keeping the
    assigned footprint), and C8 drops 100nF -> 10nF so VDDA carries exactly
    the 10nF + 1uF of DS5319 Fig. 14 p.36. Provenance recorded in
    decisions.md: cap values from the datasheet, the bead from ST
    application practice - Fig. 14 itself has no bead. Closes the last
    electrical unknown; headless ERC identical.
    [drone-flight-controller.kicad_sch]
2026-07-20 pcb: source the entire remaining BOM against the LCSC catalog
    Jellybean MPN sweep: ~142 refs across 61 groups - every IC, passive,
    LED, diode, crystal, RF inductor, ferrite, and connector now carries
    LCSC/Part/Manufacturer/Datasheet fields, resolved offline Basic-first.
    Crystals were matched on load capacitance to the repo's original
    datasheets, the polarized 10uF pair is the exact original tantalum,
    and the nRF matching network gets proper RF multilayer parts. Two
    physical deltas: Y2's footprint grows 2012 -> 3215 to fit the Basic
    Epson FC-135, and FB1/FB2's invalid "100Uhm" value becomes the
    sourced 3A 120R power bead. Sourcing gate: PASS, 0 blocking, 26
    Extended lines (~$78 max setup). ER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
    [ATMEGA238P-plus-components.kicad_sch, drone-flight-controller.kicad_sch]
2026-07-20 pcb: session state (symbol-update reverted USB shield pins)
    [drone-flight-controller.kicad_pcb, drone-flight-controller.kicad_sch]
2026-07-20 sch: make the USB shield fix immune to symbol updates
    'Update Symbols from Library' restored the global Connector lib's stale
    SH shield pin for the second time, floating both USB shells again.
    Re-apply SH->6 and make it structural: the corrected USB_B_Micro now
    lives in the project's custom-symbols library, sym-lib-table registers
    it (previously empty), and J3/J16 resolve project-locally - a future
    symbol update pulls the corrected copy by construction. Netlist
    verified: both shield pins back on GND.
    [ATMEGA238P-plus-components.kicad_sch, drone-flight-controller.kicad_sch]
2026-07-20 pcb: board sync after MPN sweep and USB shield restoration
    [drone-flight-controller.kicad_pcb]
2026-07-23 pcb: SW1-SW3 go SMD - TS-1088 (C720477, Basic) supersedes the 6x6 THT tacts
    Smaller-footprint request: ~5.6x3.0 mm single-side land vs a 6x6 body with
    four through-holes, freeing bottom copper under all three buttons on the
    2-layer board. Basic library kills one Extended feeder line and three
    hand-solder THT parts. Pad map CLEAN (2 pads <-> 2 pins, no shorted-pair
    topology). Board sync via F8 + replace-footprints to follow.
    [ATMEGA238P-plus-components.kicad_sch, drone-flight-controller.kicad_sch]
2026-07-23 pcb: F8 sync - TS-1088 SMD footprints replace the THT tacts on the board
    Includes in-progress hand placement from the same session (switch row at
    y=113.7, U8 reposition, silk font normalization). Board is mid-placement,
    unrouted: DRC noise is ratsnest + silk/text-height artifacts, none of it
    involves the swapped switches.
    [drone-flight-controller.kicad_pcb]
2026-07-23 pcb: SW4 goes right-angle - SS-12D11-G030 (C17179526) supersedes the vertical G5
    Edge-actuated master power once the drone is framed; 3A/10k-cycle vs
    2A/3k. Pad 2 = middle = common verified against the datasheet PCB layout,
    so the +12V/+12C wiring carries over; pads 4/5 are netless bracket slots.
    Board F8 sync to follow.
    [drone-flight-controller.kicad_sch]
2026-07-23 pcb: SW4 lands on K3-1204D (C145861) - the G030 was too big, so was everything else that could carry the load
    Slim 10x2.5 mm vertical slide, 5A/50k cycles: the only part found that
    passes both the size requirement and the electrical gate. The hunt is
    documented in parts-log: WJ too big, MK-12C02 only 6V, MSK12CO2 only
    50mA, SK12D07 killed by its own datasheet (300mA real vs 500mA in the
    LCSC listing). Pad 2 = middle = common, wiring unchanged.
    [drone-flight-controller.kicad_sch]
2026-07-25 provisional final component placements
    [ATMEGA238P-plus-components.kicad_sch, drone-flight-controller.kicad_pcb, drone-flight-controller.kicad_sch]
2026-07-27 copper zones and JPI logo
    [drone-flight-controller.kicad_pcb]
2026-07-27 5v net assignment
    [drone-flight-controller.kicad_pcb]
2026-07-30 correct crystals ocs placement, copper zones and routing
    [drone-flight-controller.kicad_pcb]
2026-08-06 finish drone controller pcb first pass
    [ATMEGA238P-plus-components.kicad_sch, drone-flight-controller.kicad_pcb, drone-flight-controller.kicad_sch]
2026-08-06 drc cleanup: board at 0 errors / 0 unconnected (was 40 errors + split 5V plane)
    Reroute MISO_SD_OUT off J15.5 (real short), bridge the split +5V In2 plane
    and drop sub-2mm2 islands, dedupe shared NPTH mounting holes so the fab
    drills each location once, respace the ATmega USB pair to 0.2mm, pull fence
    vias and edge silk clear of the outline, normalize silk text to the 0.8mm
    minimum and relocate 58 refs. Remaining 91 warnings are structural
    (In1-only GND fence vias), intentional (board-vs-lib divergence from the
    NPTH dedupe), or dense-cluster refs needing hand placement.
    [drone-flight-controller.kicad_pcb]
2026-08-06 button references:
    [drone-flight-controller.kicad_pcb]
2026-08-06 texts and graphics
    [drone-flight-controller.kicad_pcb]
2026-08-06 fab files /pcb/production
    [bom.csv, designators.csv, positions.csv]
2026-08-06 readme: document fab-ready state; attach 3D models for XT60, SMA, OLED
    README now reflects reality: routed 4-layer board, clean DRC/ERC, and the
    JLCPCB package in pcb/production/. Board gains vertical-mount 3D models on
    J8 (XT60-M), J17 (SMA jack, barrel up), and J11 (0.96" OLED floated 10mm
    at standoff height); STEP files live in pcb/libs/easyeda.3dshapes/ which
    stays untracked per the repo's *.step ignore rule.
    [drone-flight-controller.kicad_pcb]
2026-08-06 readme: add front/back board renders
